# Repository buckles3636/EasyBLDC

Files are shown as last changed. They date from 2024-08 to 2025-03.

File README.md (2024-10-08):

# Easy BLDC

## Overview
Easy BLDC is an open source sensorless FOC brushless dc motor driver designed for propeller thrust applications such as drones or underwater AUVS.

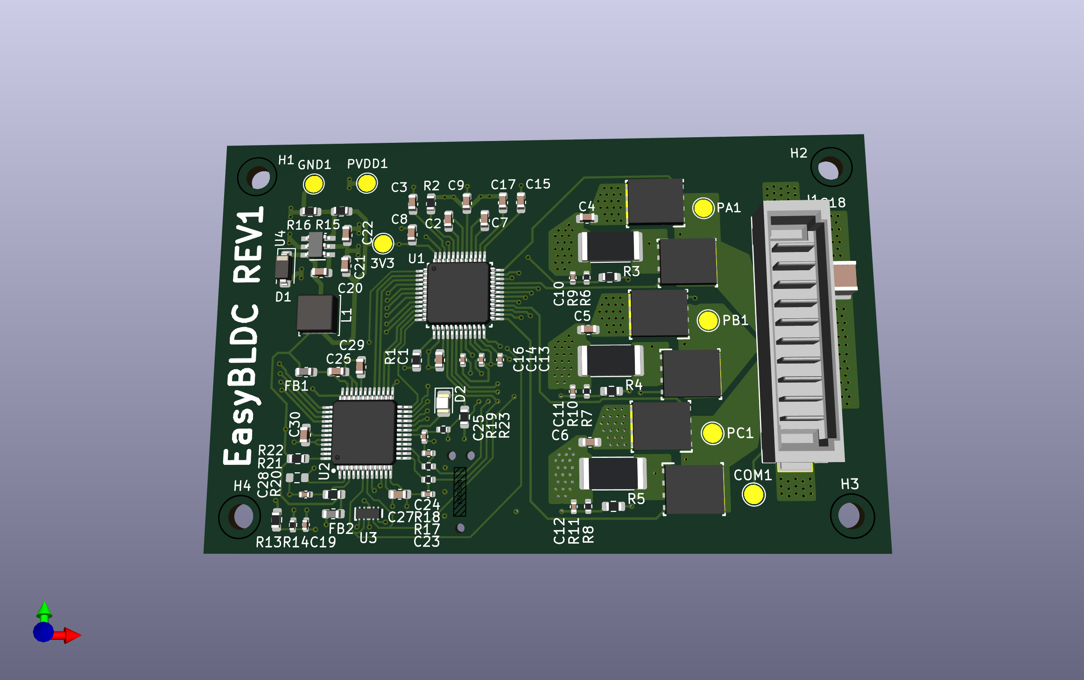
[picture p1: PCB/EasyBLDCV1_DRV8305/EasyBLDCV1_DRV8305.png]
PCB Render


## Features
* 30V Maximum Input Voltage
* 20A Maximum Continues Current (Untested)
* High current Amphenol power blade connector for board-board mounting
* High efficency FOC algorithm
* Modifiable parameters via Ti MotorWare® GUI

## Why FOC?
FOC is the most advanced of the three common algorithms. Unlike trapezoidal or sinusoidal control, which energize the motor’s phases based on predefined waveforms, FOC actively keeps tracks the stator position. This allows for precise control of both torque and speed by decoupling the motor’s magnetic field into two components: one that controls the motor's flux and the other that controls the torque. FOC is extremely efficient, especially at higher speeds, and results in smooth operation at lower speeds. 

## Key Components
* Texas Instruments DRV8305 gate driver
* Texas Instruments InstaSpin® TMS320F28027F MCU

## Ordering Guide
TODO:

## Getting Started Guide
TODO:

## Motor Tuning Guide
TODO:

## Contribution Guidelines
We welcome contributions from the broader community. To contribute:

1. **Fork the Repository**: Create your own fork of the project.
2. **Create a Feature Branch**: Make your changes in a new branch.
3. **Commit Your Changes**: Commit your changes with clear and detailed commit messages.
4. **Submit a Pull Request**: Create a pull request for your changes to be reviewed.

Please ensure your designs meet common standards and include necessary documentation and comments.

## Project Status
- Version 1: Released
- Version 2: In  Progress

## License
This project is licensed under the [MIT License](LICENSE) - see the LICENSE file for details.

## Contact
- Designer: Peter Buckley
- Email: peterbuckley3636@gmail.com

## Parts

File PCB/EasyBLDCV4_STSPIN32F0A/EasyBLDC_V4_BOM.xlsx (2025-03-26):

Designator | Footprint | Quantity | Value | Part #
C1, C10, C11, C2, C3, C6, C7, C8, C9 | 1206 | 9 | 22u 25V | CL31A226KAHNNNE
C12 | 805 | 1 | 10u 6.3V | CL21B106KQQNNNE
C13, C15, C16, C18, C4, C5 | 402 | 6 | 100n 6.3V | GRM155R60J104KA01D
C14 | 805 | 1 | 22u 6.3V | CL21A226MQQNNNE
C17 | 402 | 1 | 100n 25V | CL05B104KA5NNNC
C19, C20, C21 | 402 | 3 | 1u 25V | GRM155R61E105MA12D
D1, D2 | 402 | 2 | D | BAT54LP-7
D3 | 603 | 1 | GREEN | 150060GS75000
D4 | 603 | 1 | RED | 150060RS75000
J1 | AMPHENOL_10159560-A00221RLF | 1 |  | 10159560-A00221RLF
J2 | STLINK-V3MINIE-EDGE | 1 | STLINK-V3MINIE-EDGE
L1 |  | 1 | 22uF | MLZ2012P220WT000
Q1, Q2, Q3 | PG-TDSON-8-56-2 | 3 |  | IAUC60N04S6N031HATMA1
R1, R2, R3, R4, R5, R6 | 402 | 6 | 33 | RC0402FR-0733RL
R10, R19 | 402 | 2 | 1k | RC0402JR-071KL
R11, R12, R13, R18, R23, R7, R8, R9, R21 | 402 | 9 | 10k | RC0402JR-0710KL
R14 | 2512 | 1 | 0.001 | CRE2512-FZ-R001E-2
R15, R16, R17, R22 | 402 | 4 | 2.2k | RC0402FR-132K2L
R20 | 402 | 1 | 100k | RC0402JR-07100KL
TP1 | TestPoint_Pad_D1.5mm | 1 | TELEMETRY
TP2 | TestPoint_Pad_D1.5mm | 1 | TestPoint
U1 | DBV0005A_N | 1 |  | INA180A1IDBVR
U2 | IC_STSPIN32F0A | 1 |  | STSPIN32F0ATR

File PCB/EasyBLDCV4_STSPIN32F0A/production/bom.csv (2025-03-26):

Designator | Footprint | Quantity | Value | LCSC Part #
C1, C10, C11, C2, C3, C6, C7, C8, C9 | 1206 | 9 | 22u
C12 | 0805 | 1 | 10u
C13, C15, C16, C17, C18, C4, C5 | 0402 | 7 | 100n
C14, L1 | 0805 | 2 | 22u
C19, C20, C21 | 0402 | 3 | 1u
D1, D2 | 0402 | 2 | D
D3 | 0603 | 1 | GREEN
D4 | 0603 | 1 | RED
J1 | AMPHENOL_10159560-A00221RLF | 1 | 10159560-A00221RLF
J2 | STLINK-V3MINIE-EDGE | 1 | STLINK-V3MINIE-EDGE
Q1, Q2, Q3 | PG-TDSON-8-56-2 | 3 | IAUC60N04S6N031HATMA1
R1, R2, R3, R4, R5, R6 | 0402 | 6 | 33
R10, R19 | 0402 | 2 | 1k
R11, R12, R13, R18, R21, R23, R7, R8, R9 | 0402 | 9 | 10k
R14 | 2512 | 1 | 0.001
R15, R16, R17, R22 | 0402 | 4 | 2.2k
R20 | 0402 | 1 | 100k
TP1 | TestPoint_Pad_D1.5mm | 1 | TELEMETRY
TP2 | TestPoint_Pad_D1.5mm | 1 | TestPoint
U1 | DBV0005A_N | 1 | INA180A1IDBVR
U2 | IC_STSPIN32F0A | 1 | STSPIN32F0A

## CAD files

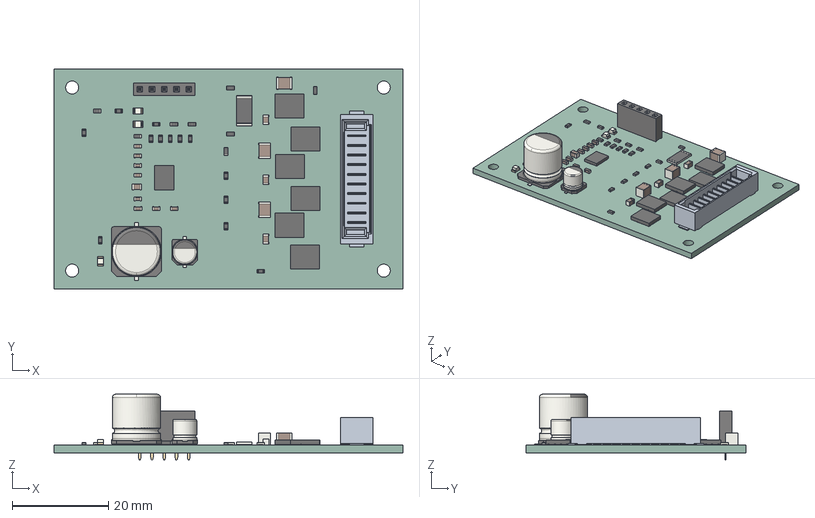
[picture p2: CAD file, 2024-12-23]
PCB/EasyBLDCV4_STSPIN32F0A/EasyBLDCV4_STSPIN32F0A.step
72.4 x 45.7 x 13.6 mm
R_0603_1608Metric x 21
DNK0008A_ASM x 6
CP_Elec_5x53
C_0603_1608Metric x 8
C_0805_2012Metric x 4
R_2512_6332Metric
REE0036A_ASM
LED_0805_2012Metric x 3
CP_Elec_10x105
C_1210_3225Metric x 3
10159560-A00221RLF
PinSocket_1x05_P254mm_Vertical
EasyBLDCV2_MCF8329_PCB

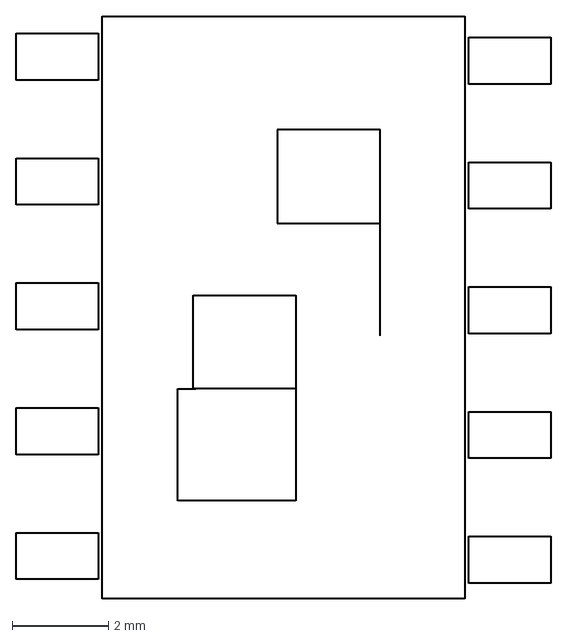
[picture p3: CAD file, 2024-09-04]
PCB/EasyBLDCV4_STSPIN32F0A/PBELogo.dxf
11.1 x 12.1 mm

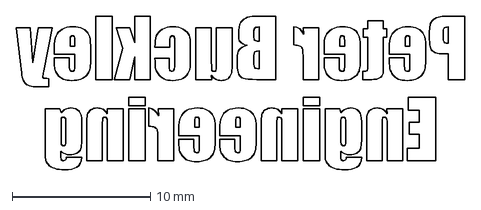
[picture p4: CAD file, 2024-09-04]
PCB/EasyBLDCV4_STSPIN32F0A/PBEText.dxf
32.5 x 11.1 mm

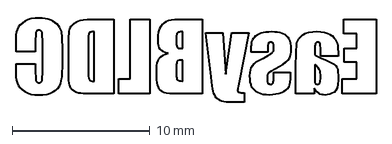
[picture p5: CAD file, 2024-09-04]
PCB/EasyBLDCV4_STSPIN32F0A/EasyESCText.dxf
26.1 x 6.17 mm

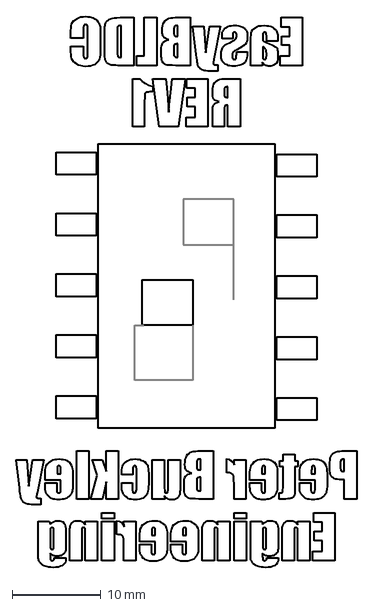
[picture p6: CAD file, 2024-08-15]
PCB/EasyBLDCV4_STSPIN32F0A/BottomLogo.dxf
38.5 x 62.2 mm

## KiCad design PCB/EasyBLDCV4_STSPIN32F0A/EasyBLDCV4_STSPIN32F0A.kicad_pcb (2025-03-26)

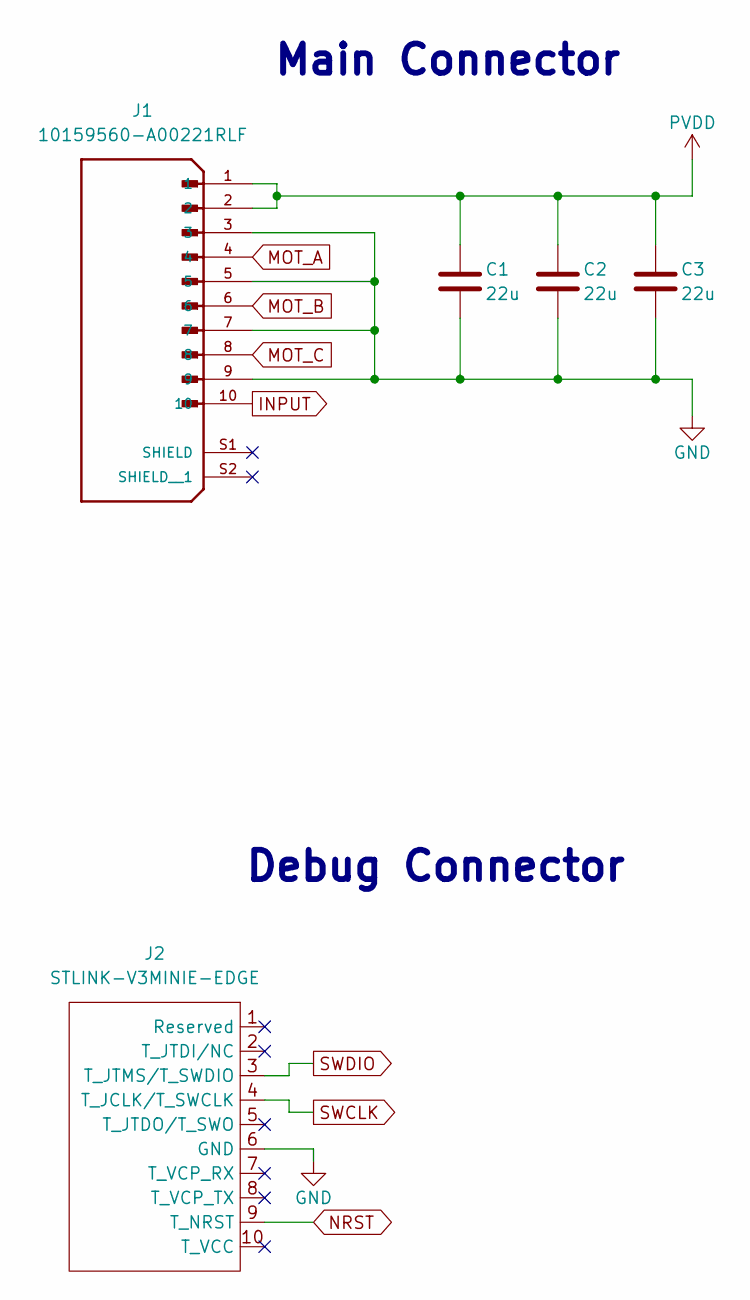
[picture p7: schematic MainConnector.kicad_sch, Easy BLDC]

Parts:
C1, C2, C3: 22u; C_1206_3216Metric
J1: 10159560-A00221RLF; AMPHENOL_10159560-A00221RLF; PARTREV C
J2: STLINK-V3MINIE-EDGE

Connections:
GND: C1.2, C2.2, C3.2, J1.3, J1.5, J1.7, J1.9, J2.6 (GND); also elsewhere on the board
INPUT: J1.10
MOT_A: J1.4; also elsewhere on the board
MOT_B: J1.6; also elsewhere on the board
MOT_C: J1.8; also elsewhere on the board
NRST: J2.9 (T_NRST); also elsewhere on the board
PVDD: C1.1, C2.1, C3.1, J1.1, J1.2; also elsewhere on the board
SWCLK: J2.4 (T_JCLK/T_SWCLK); also elsewhere on the board
SWDIO: J2.3 (T_JTMS/T_SWDIO); also elsewhere on the board

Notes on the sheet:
Main Connector
Debug Connector

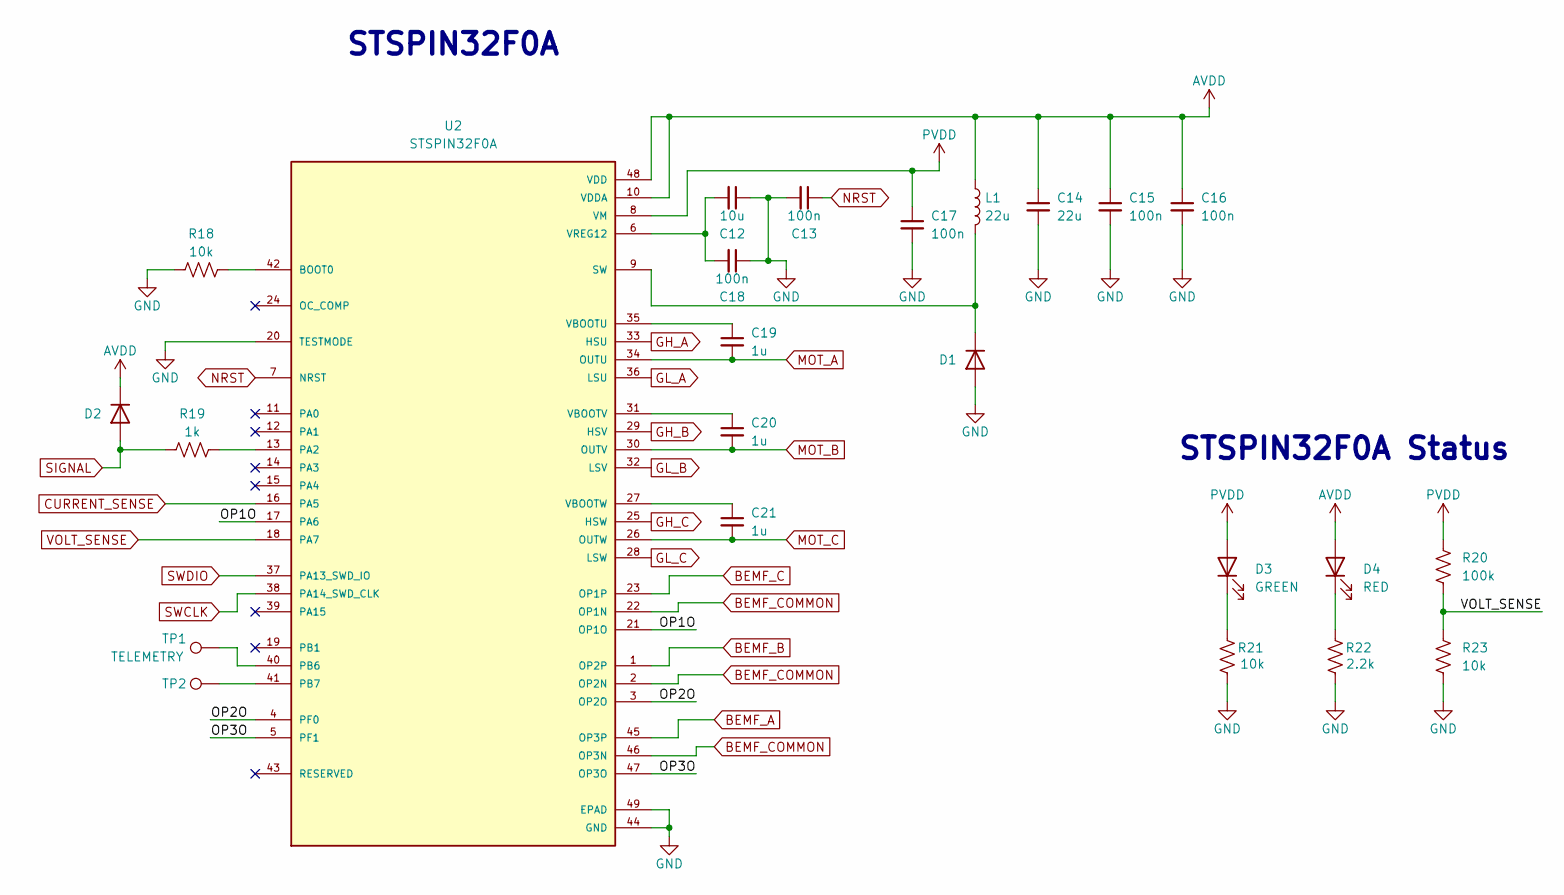
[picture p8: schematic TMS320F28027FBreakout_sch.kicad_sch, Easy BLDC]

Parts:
C12: 10u; C_0805_2012Metric
C13, C15, C16, C17, C18: 100n; C_0402_1005Metric
C14: 22u; C_0805_2012Metric
C19, C20, C21: 1u; C_0402_1005Metric
D1, D2: D; D_0402_1005Metric
D3: GREEN; LED_0603_1608Metric
D4: RED; LED_0603_1608Metric
L1: 22u; L_0805_2012Metric
R18, R21, R23: 10k; R_0402_1005Metric
R19: 1k; R_0402_1005Metric
R20: 100k; R_0402_1005Metric
R22: 2.2k; R_0402_1005Metric
TP1: TELEMETRY; TestPoint_Pad_D1.5mm
TP2: TestPoint; TestPoint_Pad_D1.5mm
U2: STSPIN32F0A; IC_STSPIN32F0A; PARTREV 2

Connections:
/MCU/OP1O: U2.17 (PA6), U2.21 (OP1O)
/MCU/OP2O: U2.3 (OP2O), U2.4 (PF0)
/MCU/OP3O: U2.5 (PF1), U2.47 (OP3O)
AVDD: C14.1, C15.1, C16.1, D2.1 (K), D4.2 (A), L1.1, U2.10 (VDDA), U2.48 (VDD); also elsewhere on the board
BEMF_A: U2.45 (OP3P); also elsewhere on the board
BEMF_B: U2.1 (OP2P); also elsewhere on the board
BEMF_C: U2.23 (OP1P); also elsewhere on the board
BEMF_COMMON: U2.2 (OP2N), U2.22 (OP1N), U2.46 (OP3N); also elsewhere on the board
CURRENT_SENSE: U2.16 (PA5); also elsewhere on the board
GH_A: U2.33 (HSU); also elsewhere on the board
GH_B: U2.29 (HSV); also elsewhere on the board
GH_C: U2.25 (HSW); also elsewhere on the board
GL_A: U2.36 (LSU); also elsewhere on the board
GL_B: U2.32 (LSV); also elsewhere on the board
GL_C: U2.28 (LSW); also elsewhere on the board
GND: C12.1, C13.2, C14.2, C15.2, C16.2, C17.2, C18.1, D1.2 (A), R18.1, R21.1, R22.1, R23.2, U2.20 (TESTMODE), U2.44 (GND), U2.49 (EPAD); also elsewhere on the board
MOT_A: C19.2, U2.34 (OUTU); also elsewhere on the board
MOT_B: C20.2, U2.30 (OUTV); also elsewhere on the board
MOT_C: C21.2, U2.26 (OUTW); also elsewhere on the board
NRST: C13.1, U2.7 (NRST); also elsewhere on the board
unnamed: D1.1 (K), L1.2, U2.9 (SW)
unnamed: D3.1 (K), R21.2
unnamed: D4.1 (K), R22.2
unnamed: R18.2, U2.42 (BOOT0)
unnamed: R19.2, U2.13 (PA2)
unnamed: TP1.1, U2.40 (PB6)
unnamed: TP2.1, U2.41 (PB7)
unnamed: C19.1, U2.35 (VBOOTU)
unnamed: C20.1, U2.31 (VBOOTV)
unnamed: C21.1, U2.27 (VBOOTW)
unnamed: C12.2, C18.2, U2.6 (VREG12)
PVDD: C17.1, D3.2 (A), R20.1, U2.8 (VM); also elsewhere on the board
SIGNAL: D2.2 (A), R19.1
SWCLK: U2.38 (PA14_SWD_CLK); also elsewhere on the board
SWDIO: U2.37 (PA13_SWD_IO); also elsewhere on the board
VOLT_SENSE: R20.2, R23.1, U2.18 (PA7)

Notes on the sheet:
STSPIN32F0A Status
STSPIN32F0A

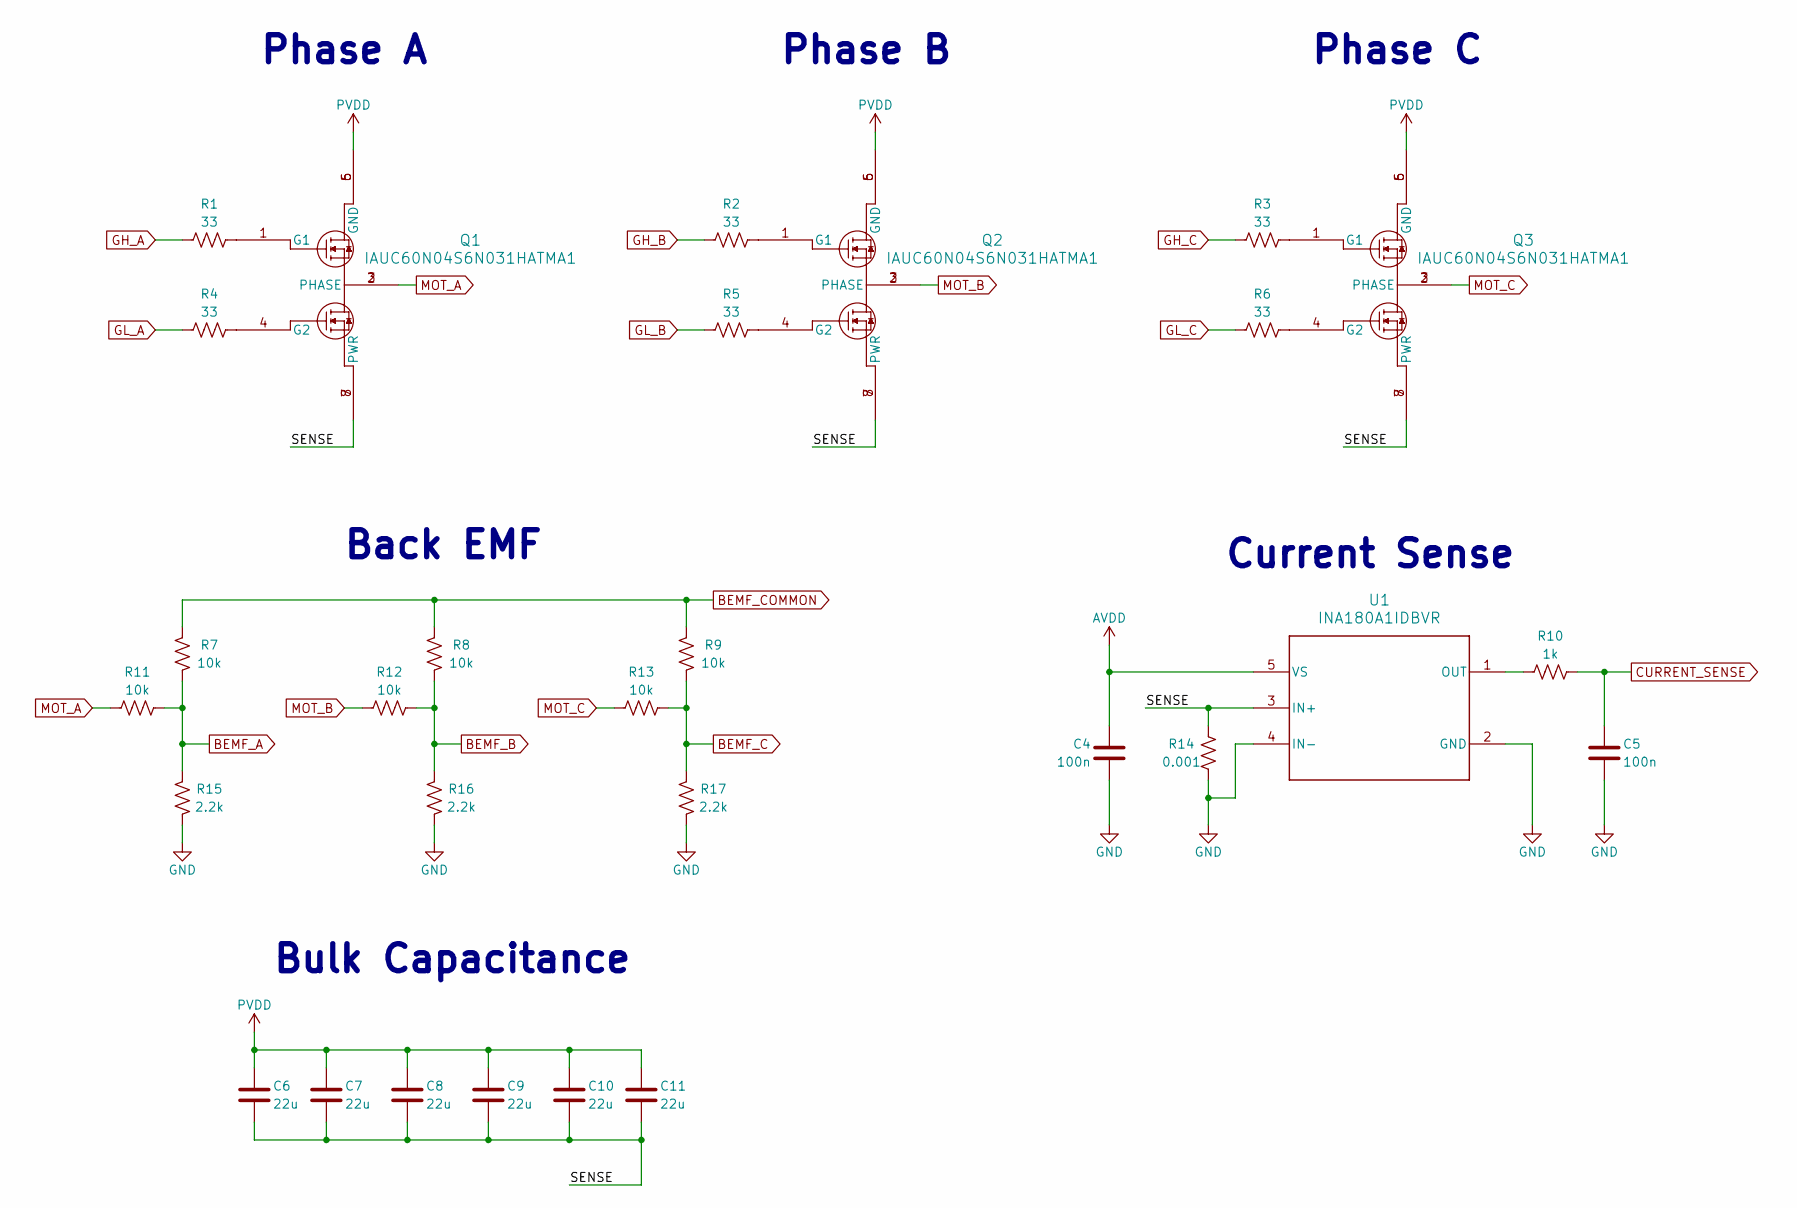
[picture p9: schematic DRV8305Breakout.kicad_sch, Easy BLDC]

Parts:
C4, C5: 100n; C_0402_1005Metric
C6, C7, C8, C9, C10, C11: 22u; C_1206_3216Metric
Q1, Q2, Q3: IAUC60N04S6N031HATMA1; PG-TDSON-8-56-2
R1, R2, R3, R4, R5, R6: 33; R_0402_1005Metric
R7, R8, R9, R11, R12, R13: 10k; R_0402_1005Metric
R10: 1k; R_0402_1005Metric
R14: 0.001; R_2512_6332Metric
R15, R16, R17: 2.2k; R_0402_1005Metric
U1: INA180A1IDBVR; DBV0005A_N

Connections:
/Power Stage/SENSE: C6.2, C7.2, C8.2, C9.2, C10.2, C11.2, Q1.7 (PWR), Q1.8 (PWR), Q2.7 (PWR), Q2.8 (PWR), Q3.7 (PWR), Q3.8 (PWR), R14.2, U1.3 (IN+)
AVDD: C4.1, U1.5 (VS); also elsewhere on the board
BEMF_A: R7.1, R11.2, R15.2; also elsewhere on the board
BEMF_B: R8.1, R12.2, R16.2; also elsewhere on the board
BEMF_C: R9.1, R13.2, R17.2; also elsewhere on the board
BEMF_COMMON: R7.2, R8.2, R9.2; also elsewhere on the board
CURRENT_SENSE: C5.1, R10.2; also elsewhere on the board
GH_A: R1.1; also elsewhere on the board
GH_B: R2.1; also elsewhere on the board
GH_C: R3.1; also elsewhere on the board
GL_A: R4.1; also elsewhere on the board
GL_B: R5.1; also elsewhere on the board
GL_C: R6.1; also elsewhere on the board
GND: C4.2, C5.2, R14.1, R15.1, R16.1, R17.1, U1.2 (GND), U1.4 (IN-); also elsewhere on the board
MOT_A: Q1.2 (PHASE), Q1.3 (PHASE), R11.1; also elsewhere on the board
MOT_B: Q2.2 (PHASE), Q2.3 (PHASE), R12.1; also elsewhere on the board
MOT_C: Q3.2 (PHASE), Q3.3 (PHASE), R13.1; also elsewhere on the board
unnamed: Q1.1 (G1), R1.2
unnamed: Q1.4 (G2), R4.2
unnamed: Q2.1 (G1), R2.2
unnamed: Q2.4 (G2), R5.2
unnamed: Q3.1 (G1), R3.2
unnamed: Q3.4 (G2), R6.2
unnamed: R10.1, U1.1 (OUT)
PVDD: C6.1, C7.1, C8.1, C9.1, C10.1, C11.1, Q1.5 (GND), Q1.6 (GND), Q2.5 (GND), Q2.6 (GND), Q3.5 (GND), Q3.6 (GND); also elsewhere on the board

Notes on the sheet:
Current Sense
Phase C
Bulk Capacitance
Phase B
Back EMF
Phase A

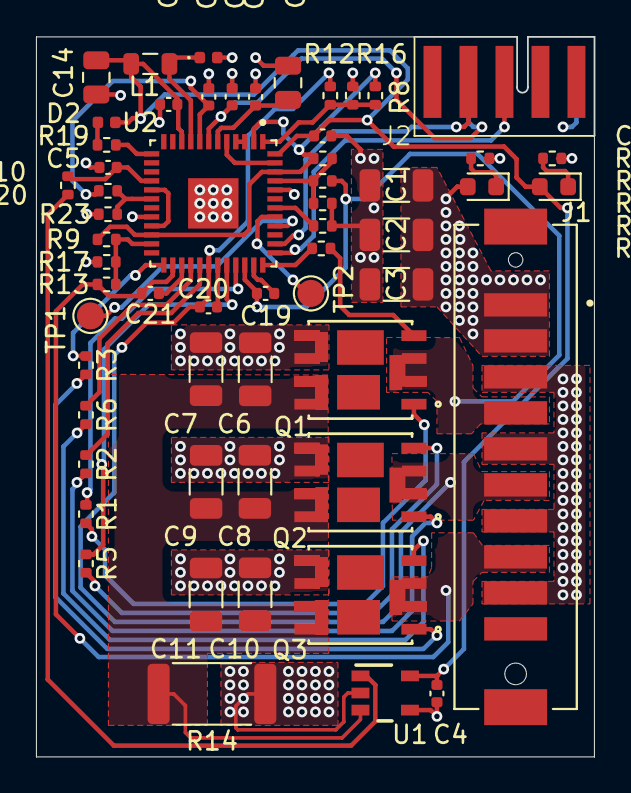
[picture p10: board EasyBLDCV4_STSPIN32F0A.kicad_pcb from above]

Board: 4 copper layers, 31.0 x 40.0 mm, 58 parts (0 on the bottom side), 44 nets.

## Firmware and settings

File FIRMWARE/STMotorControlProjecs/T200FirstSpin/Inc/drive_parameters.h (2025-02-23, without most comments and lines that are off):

#define DRIVE_PARAMETERS_H
#define MAX_APPLICATION_SPEED_RPM           1062
#define MIN_APPLICATION_SPEED_RPM           0
#define M1_SS_MEAS_ERRORS_BEFORE_FAULTS     3
#define VARIANCE_THRESHOLD                  0.25
#define F1                                  16384
#define F2                                  4096
#define F1_LOG                              LOG2((16384))
#define F2_LOG                              LOG2((4096))
#define GAIN1                               -22016
#define GAIN2                               17800
#define PLL_KP_GAIN                         494
#define PLL_KI_GAIN                         22
#define PLL_KPDIV                           16384
#define PLL_KPDIV_LOG                       LOG2((PLL_KPDIV))
#define PLL_KIDIV                           65535
#define PLL_KIDIV_LOG                       LOG2((PLL_KIDIV))
#define STO_FIFO_DEPTH_DPP                  64
#define STO_FIFO_DEPTH_DPP_LOG              LOG2((64))
#define STO_FIFO_DEPTH_UNIT                 64
#define M1_BEMF_CONSISTENCY_TOL             64
#define M1_BEMF_CONSISTENCY_GAIN            64
#define PARK_ANGLE_COMPENSATION_FACTOR      0
#define REV_PARK_ANGLE_COMPENSATION_FACTOR  0
#define PWM_FREQUENCY                       16000
#define PWM_FREQ_SCALING                    1
#define LOW_SIDE_SIGNALS_ENABLING           LS_PWM_TIMER
#define SW_DEADTIME_NS                      750
#define REGULATION_EXECUTION_RATE           1
#define ISR_FREQUENCY_HZ                    (PWM_FREQUENCY/REGULATION_EXECUTION_RATE)
#define PID_TORQUE_KP_DEFAULT               3719
#define PID_TORQUE_KI_DEFAULT               3099
#define PID_TORQUE_KD_DEFAULT               100
#define PID_FLUX_KP_DEFAULT                 3719
#define PID_FLUX_KI_DEFAULT                 3099
#define PID_FLUX_KD_DEFAULT                 100
#define TF_KPDIV                            4096
#define TF_KIDIV                            16384
#define TF_KDDIV                            8192
#define TF_KPDIV_LOG                        LOG2((4096))
#define TF_KIDIV_LOG                        LOG2((16384))
#define TF_KDDIV_LOG                        LOG2((8192))
#define TFDIFFERENTIAL_TERM_ENABLING        DISABLE
#define PID_SPEED_KP_DEFAULT                2174/(SPEED_UNIT/10)
#define PID_SPEED_KI_DEFAULT                876/(SPEED_UNIT/10)
#define PID_SPEED_KD_DEFAULT                0/(SPEED_UNIT/10)
#define SPEED_LOOP_FREQUENCY_HZ             (uint16_t)1000
#define SP_KPDIV                            8
#define SP_KIDIV                            16384
#define SP_KDDIV                            16
#define SP_KPDIV_LOG                        LOG2((8))
#define SP_KIDIV_LOG                        LOG2((16384))
#define SP_KDDIV_LOG                        LOG2((16))
#define PID_SPEED_INTEGRAL_INIT_DIV         1
#define SPD_DIFFERENTIAL_TERM_ENABLING      DISABLE
#define IQMAX_A                             8
#define DEFAULT_CONTROL_MODE                MCM_SPEED_MODE
#define DEFAULT_TARGET_SPEED_RPM            383
#define DEFAULT_TARGET_SPEED_UNIT           (DEFAULT_TARGET_SPEED_RPM*SPEED_UNIT/U_RPM)
#define DEFAULT_TORQUE_COMPONENT_A          0
#define DEFAULT_FLUX_COMPONENT_A            0
#define OV_VOLTAGE_THRESHOLD_V              28
#define UD_VOLTAGE_THRESHOLD_V              8
#ifdef NOT_IMPLEMENTED
#define ON_OVER_VOLTAGE                     TURN_OFF_PWM
#endif
#define OV_TEMPERATURE_THRESHOLD_C          70
#define OV_TEMPERATURE_HYSTERESIS_C         10
#define HW_OV_CURRENT_PROT_BYPASS           DISABLE
#define OVP_INVERTINGINPUT_MODE             INT_MODE
#define OVP_INVERTINGINPUT_MODE2            INT_MODE
#define OVP_SELECTION                       COMP_Selection_COMP1
#define OVP_SELECTION2                      COMP_Selection_COMP1
#define PHASE1_DURATION                     1000
#define PHASE1_FINAL_SPEED_UNIT             (0*SPEED_UNIT/U_RPM)
#define PHASE1_FINAL_CURRENT_A              8
#define PHASE2_DURATION                     850
#define PHASE2_FINAL_SPEED_UNIT             (425*SPEED_UNIT/U_RPM)
#define PHASE2_FINAL_CURRENT_A              8
#define PHASE3_DURATION                     0
#define PHASE3_FINAL_SPEED_UNIT             (425*SPEED_UNIT/U_RPM)
#define PHASE3_FINAL_CURRENT_A              8
#define PHASE4_DURATION                     0
#define PHASE4_FINAL_SPEED_UNIT             (425*SPEED_UNIT/U_RPM)
#define PHASE4_FINAL_CURRENT_A              8
#define PHASE5_DURATION                     0
#define PHASE5_FINAL_SPEED_UNIT             (425*SPEED_UNIT/U_RPM)
#define PHASE5_FINAL_CURRENT_A              8
#define ENABLE_SL_ALGO_FROM_PHASE           2
#define STARTING_ANGLE_DEG                  0
#define OBS_MINIMUM_SPEED_RPM               383
#define NB_CONSECUTIVE_TESTS                2
#define SPEED_BAND_UPPER_LIMIT              17
#define SPEED_BAND_LOWER_LIMIT              15
#define TRANSITION_DURATION                 25
#define  M1_VBUS_SAMPLING_TIME              LL_ADC_SAMPLING_CYCLE(47)
#define  M1_TEMP_SAMPLING_TIME              LL_ADC_SAMPLING_CYCLE(47)
#define ADC_SAMPLING_CYCLES                 (6 + SAMPLING_CYCLE_CORRECTION)

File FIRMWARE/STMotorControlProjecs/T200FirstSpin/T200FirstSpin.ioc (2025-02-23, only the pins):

Mcu.UserName=STM32G431CBUx
PA0.GPIO_Label=M1_BUS_VOLTAGE
PA0.Signal=ADC1_IN1
PA1.GPIO_Label=M1_CURR_SHUNT_U
PA1.Signal=SharedAnalog_PA1
PA10.GPIO_Label=M1_PWM_WH
PA10.Signal=S_TIM1_CH3
PA12.GPIO_Label=M1_PWM_VL
PA12.Signal=TIM1_CH2N
PA13.GPIO_Label=TMS
PA13.Signal=SYS_JTMS-SWDIO
PA14.GPIO_Label=TCK
PA14.Signal=SYS_JTCK-SWCLK
PA2.GPIO_Label=M1_OPAMP1_OUT
PA2.Signal=SharedAnalog_PA2
PA3.GPIO_Label=M1_OPAMP1_INT_GAIN
PA3.Signal=OPAMP1_VINM0
PA5.GPIO_Label=M1_OPAMP2_INT_GAIN
PA5.Signal=OPAMP2_VINM0
PA6.GPIO_Label=M1_OPAMP2_OUT
PA6.Signal=SharedAnalog_PA6
PA7.GPIO_Label=M1_CURR_SHUNT_V
PA7.Signal=SharedAnalog_PA7
PA8.GPIO_Label=M1_PWM_UH
PA8.Signal=S_TIM1_CH1
PA9.GPIO_Label=M1_PWM_VH
PA9.Signal=S_TIM1_CH2
PB0.GPIO_Label=M1_CURR_SHUNT_W
PB0.Signal=SharedAnalog_PB0
PB1.GPIO_Label=M1_OPAMP3_OUT
PB1.Signal=SharedAnalog_PB1
PB14.GPIO_Label=M1_TEMPERATURE
PB14.Signal=ADC1_IN5
PB15.GPIO_Label=M1_PWM_WL
PB15.Signal=TIM1_CH3N
PB2.GPIO_Label=M1_OPAMP3_INT_GAIN
PB2.Signal=OPAMP3_VINM0
PB3.GPIO_Label=UART_TX
PB3.Signal=USART2_TX
PB4.GPIO_Label=UART_RX
PB4.Signal=USART2_RX
PC10.GPIO_Label=Start/Stop [PushButton]
PC10.Signal=GPXTI10
PC13.GPIO_Label=M1_PWM_UL
PC13.Signal=TIM1_CH1N
PF0-OSC_IN.Signal=RCC_OSC_IN
PF1-OSC_OUT.Signal=RCC_OSC_OUT

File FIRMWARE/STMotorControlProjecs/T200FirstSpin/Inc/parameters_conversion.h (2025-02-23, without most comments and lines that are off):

#define PARAMETERS_CONVERSION_H
#include "mc_math.h"
#include "parameters_conversion_g4xx.h"
#include "pmsm_motor_parameters.h"
#include "drive_parameters.h"
#include "power_stage_parameters.h"
#define CURRENT_CONV_FACTOR                 (uint16_t)((65536.0 * RSHUNT * AMPLIFICATION_GAIN)/ADC_REFERENCE_VOLTAGE)
#define CURRENT_CONV_FACTOR_INV             (1.0 / ((65536.0 * RSHUNT * AMPLIFICATION_GAIN) / ADC_REFERENCE_VOLTAGE))
#define NOMINAL_CURRENT                     (NOMINAL_CURRENT_A * CURRENT_CONV_FACTOR)
#define ADC_REFERENCE_VOLTAGE               3.3
#define M1_MAX_READABLE_CURRENT  (ADC_REFERENCE_VOLTAGE / (2 * RSHUNT * AMPLIFICATION_GAIN))
#define TF_REGULATION_RATE                  (uint32_t)((uint32_t)(PWM_FREQUENCY) / (REGULATION_EXECUTION_RATE))
#define TF_REGULATION_RATE_SCALED           (uint16_t)((uint32_t)(PWM_FREQUENCY) / (REGULATION_EXECUTION_RATE\
                                            * PWM_FREQ_SCALING))
#define DPP_CONV_FACTOR                     (65536 / PWM_FREQ_SCALING)
#define ID_DEMAG                            (ID_DEMAG_A * CURRENT_CONV_FACTOR)
#define IQMAX                               (IQMAX_A * CURRENT_CONV_FACTOR)
#define DEFAULT_TORQUE_COMPONENT            (DEFAULT_TORQUE_COMPONENT_A * CURRENT_CONV_FACTOR)
#define DEFAULT_FLUX_COMPONENT              (DEFAULT_FLUX_COMPONENT_A * CURRENT_CONV_FACTOR)
#define REP_COUNTER                         (uint16_t)((REGULATION_EXECUTION_RATE * 2u) - 1u)
#define SYS_TICK_FREQUENCY                  (uint16_t)2000
#define UI_TASK_FREQUENCY_HZ                10U
#define PHASE1_FINAL_CURRENT                (PHASE1_FINAL_CURRENT_A * CURRENT_CONV_FACTOR)
#define PHASE2_FINAL_CURRENT                (PHASE2_FINAL_CURRENT_A * CURRENT_CONV_FACTOR)
#define PHASE3_FINAL_CURRENT                (PHASE3_FINAL_CURRENT_A * CURRENT_CONV_FACTOR)
#define PHASE4_FINAL_CURRENT                (PHASE4_FINAL_CURRENT_A * CURRENT_CONV_FACTOR)
#define PHASE5_FINAL_CURRENT                (PHASE5_FINAL_CURRENT_A * CURRENT_CONV_FACTOR)
#define MEDIUM_FREQUENCY_TASK_RATE          (uint16_t)SPEED_LOOP_FREQUENCY_HZ
#define MF_TASK_OCCURENCE_TICKS             (SYS_TICK_FREQUENCY / SPEED_LOOP_FREQUENCY_HZ) - 1u
#define UI_TASK_OCCURENCE_TICKS             (SYS_TICK_FREQUENCY / UI_TASK_FREQUENCY_HZ) - 1u
#define SERIALCOM_TIMEOUT_OCCURENCE_TICKS   (SYS_TICK_FREQUENCY / SERIAL_COM_TIMEOUT_INVERSE) - 1u
#define SERIALCOM_ATR_TIME_TICKS            (uint16_t)(((SYS_TICK_FREQUENCY * SERIAL_COM_ATR_TIME_MS) / 1000u) - 1u)
#define MAX_BEMF_VOLTAGE                    (uint16_t)((MAX_APPLICATION_SPEED_RPM * 1.2 *\
                                            MOTOR_VOLTAGE_CONSTANT * SQRT_2) / (1000u * SQRT_3))
#define MAX_VOLTAGE                         (int16_t)((ADC_REFERENCE_VOLTAGE / SQRT_3) / VBUS_PARTITIONING_FACTOR)
#define MAX_CURRENT                         (ADC_REFERENCE_VOLTAGE / (2 * RSHUNT * AMPLIFICATION_GAIN))
#define OBS_MINIMUM_SPEED_UNIT              (uint16_t)((OBS_MINIMUM_SPEED_RPM * SPEED_UNIT) / U_RPM)
#define MAX_APPLICATION_SPEED_UNIT          ((MAX_APPLICATION_SPEED_RPM * SPEED_UNIT) / U_RPM)
#define MIN_APPLICATION_SPEED_UNIT          ((MIN_APPLICATION_SPEED_RPM * SPEED_UNIT) / U_RPM)
#define C1                                  (int32_t)((((int16_t)F1) * RS) / (LS * TF_REGULATION_RATE))
#define C2                                  (int32_t)GAIN1
#define C3                                  (int32_t)((((int16_t)F1) * MAX_BEMF_VOLTAGE)\
                                            / (LS * MAX_CURRENT * TF_REGULATION_RATE))
#define C4                                  (int32_t)GAIN2
#define C5                                  (int32_t)((((int16_t)F1) * MAX_VOLTAGE)\
                                            / (LS * MAX_CURRENT * TF_REGULATION_RATE))
#define PERCENTAGE_FACTOR                   (uint16_t)(VARIANCE_THRESHOLD*128u)
#define HFI_MINIMUM_SPEED                   (uint16_t) (HFI_MINIMUM_SPEED_RPM/6u)
#define MAX_APPLICATION_SPEED_UNIT2         ((MAX_APPLICATION_SPEED_RPM2 * SPEED_UNIT) / U_RPM)
#define MIN_APPLICATION_SPEED_UNIT2         ((MIN_APPLICATION_SPEED_RPM2 * SPEED_UNIT) / U_RPM)
#define OVERVOLTAGE_THRESHOLD_d             (uint16_t)(OV_VOLTAGE_THRESHOLD_V * 65535 /\
                                            (ADC_REFERENCE_VOLTAGE / VBUS_PARTITIONING_FACTOR))
#define OVERVOLTAGE_THRESHOLD_LOW_d         (uint16_t)(OV_VOLTAGE_THRESHOLD_V * 65535 /\
                                            (ADC_REFERENCE_VOLTAGE / VBUS_PARTITIONING_FACTOR))
#define UNDERVOLTAGE_THRESHOLD_d            (uint16_t)((UD_VOLTAGE_THRESHOLD_V * 65535) /\
                                            ((uint16_t)(ADC_REFERENCE_VOLTAGE / VBUS_PARTITIONING_FACTOR)))
#define INT_SUPPLY_VOLTAGE                  (uint16_t)(65536 / ADC_REFERENCE_VOLTAGE)
#define DELTA_TEMP_THRESHOLD                (OV_TEMPERATURE_THRESHOLD_C - T0_C)
#define DELTA_V_THRESHOLD                   (dV_dT * DELTA_TEMP_THRESHOLD)
#define OV_TEMPERATURE_THRESHOLD_d          ((V0_V + DELTA_V_THRESHOLD) * INT_SUPPLY_VOLTAGE)
#define DELTA_TEMP_HYSTERESIS               (OV_TEMPERATURE_HYSTERESIS_C)
#define DELTA_V_HYSTERESIS                  (dV_dT * DELTA_TEMP_HYSTERESIS)
#define OV_TEMPERATURE_HYSTERESIS_d         (DELTA_V_HYSTERESIS * INT_SUPPLY_VOLTAGE)
#define PWM_PERIOD_CYCLES                   (uint16_t)(((uint32_t)ADV_TIM_CLK_MHz * (uint32_t)1000000u\
                                            / ((uint32_t)(PWM_FREQUENCY))) & (uint16_t)0xFFFE)
#define DEADTIME_NS                         SW_DEADTIME_NS
#define DEAD_TIME_ADV_TIM_CLK_MHz           (ADV_TIM_CLK_MHz * TIM_CLOCK_DIVIDER)
#define DEAD_TIME_COUNTS_1                  (DEAD_TIME_ADV_TIM_CLK_MHz * DEADTIME_NS / 1000uL)
#if (DEAD_TIME_COUNTS_1 <= 255)
#define DEAD_TIME_COUNTS                    (uint16_t)DEAD_TIME_COUNTS_1
#elif (DEAD_TIME_COUNTS_1 <= 508)
#define DEAD_TIME_COUNTS                    (uint16_t)(((DEAD_TIME_ADV_TIM_CLK_MHz * DEADTIME_NS/2) /1000uL) + 128)
#elif (DEAD_TIME_COUNTS_1 <= 1008)
#define DEAD_TIME_COUNTS                    (uint16_t)(((DEAD_TIME_ADV_TIM_CLK_MHz * DEADTIME_NS/8) /1000uL) + 320)
#elif (DEAD_TIME_COUNTS_1 <= 2015)
#define DEAD_TIME_COUNTS                    (uint16_t)(((DEAD_TIME_ADV_TIM_CLK_MHz * DEADTIME_NS/16) /1000uL) + 384)
#else
#define DEAD_TIME_COUNTS 510
#endif
#define DTCOMPCNT                           (uint16_t)((DEADTIME_NS * ADV_TIM_CLK_MHz) / 2000)
#define TON_NS                              500
#define TOFF_NS                             500
#define TON                                 (uint16_t)((TON_NS * ADV_TIM_CLK_MHz)  / 2000)
#define TOFF                                (uint16_t)((TOFF_NS * ADV_TIM_CLK_MHz) / 2000)
#define SAMPLING_TIME                       ((ADC_SAMPLING_CYCLES * ADV_TIM_CLK_MHz) / ADC_CLK_MHz)
#define TRISE                               ((TRISE_NS * ADV_TIM_CLK_MHz)/1000uL)
#define TDEAD                               ((uint16_t)((DEADTIME_NS * ADV_TIM_CLK_MHz)/1000))
#define TNOISE                              ((uint16_t)((TNOISE_NS*ADV_TIM_CLK_MHz)/1000))
#define HTMIN 1
#define TW_AFTER                            ((uint16_t)(((DEADTIME_NS+MAX_TNTR_NS)*ADV_TIM_CLK_MHz)/1000UL))
#define MAX_TWAIT                           ((uint16_t)((TW_AFTER - SAMPLING_TIME)/2))
#define TW_BEFORE                           ((uint16_t)((ADC_TRIG_CONV_LATENCY_CYCLES + ADC_SAMPLING_CYCLES)\
                                            * ADV_TIM_CLK_MHz) / ADC_CLK_MHz  + 1u)
#define TW_BEFORE_R3_1                      ((uint16_t)((ADC_TRIG_CONV_LATENCY_CYCLES + (ADC_SAMPLING_CYCLES * 2)\
                                            + ADC_SAR_CYCLES) * ADV_TIM_CLK_MHz) / ADC_CLK_MHz  + 1u)
#define M1_VIRTUAL_HEAT_SINK_TEMPERATURE_VALUE 25u
#define M1_TEMP_SW_FILTER_BW_FACTOR         250u
#define PQD_CONVERSION_FACTOR               (float_t)(((1.732 * ADC_REFERENCE_VOLTAGE) /\
                                            (RSHUNT * AMPLIFICATION_GAIN)) / 65536.0f)
#define DAC_ENABLE
#define DAC_OP_ENABLE
#define FW_ENABLE
#define DIFFTERM_ENABLE
#define MAIN_SCFG                           UI_SCODE_STO_PLL
#define AUX_SCFG                               0x0
#define PLLTUNING_ENABLE
#define UI_CFGOPT_PFC_ENABLE
#define UI_CONFIG_M1                        (UI_CFGOPT_NONE DAC_OP_ENABLE FW_ENABLE DIFFTERM_ENABLE\
                                            | (MAIN_SCFG << MAIN_SCFG_POS)\
                                            | (AUX_SCFG << AUX_SCFG_POS)\
                                            | UI_CFGOPT_SETIDINSPDMODE PLLTUNING_ENABLE UI_CFGOPT_PFC_ENABLE\
                                            | UI_CFGOPT_PLLTUNING)
#define UI_CONFIG_M2
#define DIN_ACTIVE_LOW                      Bit_RESET
#define DIN_ACTIVE_HIGH                     Bit_SET
#define DOUT_ACTIVE_HIGH                    DOutputActiveHigh
#define DOUT_ACTIVE_LOW                     DOutputActiveLow
#define LPF_FILT_CONST                      ((int16_t)(32767 * 0.5))
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

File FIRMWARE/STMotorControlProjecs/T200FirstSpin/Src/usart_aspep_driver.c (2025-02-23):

/**
  ******************************************************************************
  * @file    usart_aspep_driver.c
  * @author  Motor Control SDK Team, ST Microelectronics
  * @brief   This file provides firmware functions that implement the uart driver for the aspep protocol
  *
  *
  ******************************************************************************
  * @attention
  *
  * <h2><center>&copy; Copyright (c) 2024 STMicroelectronics.
  * All rights reserved.</center></h2>
  *
  * This software component is licensed by ST under Ultimate Liberty license
  * SLA0044, the "License"; You may not use this file except in compliance with
  * the License. You may obtain a copy of the License at:
  *                             www.st.com/SLA0044
  *
  ******************************************************************************
  */

#include <stdint.h>
#include "mc_stm_types.h"
#include "usart_aspep_driver.h"
#include "aspep.h"

void UASPEP_TX_INIT(UASPEP_Handle_t *pHandle);
void UASPEP_RX_INIT(UASPEP_Handle_t *pHandle);

/** @addtogroup MCSDK
  * @{
  */

/** @addtogroup MCP
  * @{
  */

/**
  * @brief  Initialization of the Hardware used for data transmission and reception.
  *
  * @param  pHandle Handler of the current instance of the UASPEP component
  */
void UASPEP_INIT(void *pHWHandle)
{
  UASPEP_Handle_t *pHandle = (UASPEP_Handle_t *)pHWHandle; //cstat !MISRAC2012-Rule-11.5
  UASPEP_RX_INIT(pHandle);
  UASPEP_TX_INIT(pHandle);
}

/**
  * @brief  Configures the Hardware used for data transmission to controller.
  *
  * @param  pHandle Handler of the current instance of the UASPEP component
  */
void UASPEP_TX_INIT(UASPEP_Handle_t *pHandle)
{
#ifdef NULL_PTR_CHECK_USA_ASP_DRV
  if (NULL == pHandle)
  {
    /* Nothing to do */
  }
  else
  {
#endif
    /* Enable DMA UART */
    LL_USART_ClearFlag_TC(pHandle->USARTx);
    LL_USART_EnableIT_TC(pHandle->USARTx);

    /* Enable DMA UART to start the TX request */
    LL_USART_EnableDMAReq_TX(pHandle->USARTx);

    /* Write the USART_TDR register address in the DMA control register to configure it as
     * the destination of the transfer */
    //cstat !MISRAC2012-Rule-11.4
    LL_DMA_SetPeriphAddress(pHandle->txDMA, pHandle->txChannel, (uint32_t)&pHandle->USARTx->TDR);

    /* Clear UART ISR */
    LL_USART_ClearFlag_TC(pHandle->USARTx);

    /* DMA end of transfer on UART TX channel completion is not activated */
    /* We prefer to activate UART TC itself to avoid to trig IT while queued data are still to be transmitted */
#ifdef NULL_PTR_CHECK_USA_ASP_DRV
  }
#endif
}

/**
  * @brief  Configures the Hardware used for data reception from controller.
  *
  * @param  pHandle Handler of the current instance of the UASPEP component
  */
void UASPEP_RX_INIT(UASPEP_Handle_t *pHandle)
{
#ifdef NULL_PTR_CHECK_USA_ASP_DRV
  if (NULL == pHandle)
  {
    /* Nothing to do */
  }
  else
  {
#endif
    /* DMA interrupt not used for all families */
    /* Enable DMA end of transfer on UART RX channel completion */
    /* LL_DMA_EnableIT_TC(pHandle->rxDMA, pHandle->rxChannel) */
    /* Enable Error interrupt (EIE) to unmask Overrun interrupt */
    LL_USART_EnableIT_ERROR(pHandle->USARTx);

    /* Write the USART_RDR register address in the DMA control register to configure it as
     * the source of the transfer */
    //cstat !MISRAC2012-Rule-11.4
    LL_DMA_SetPeriphAddress(pHandle->rxDMA, pHandle->rxChannel, (uint32_t)&pHandle->USARTx->RDR);

    /* Clear UART ISR */
    LL_USART_ClearFlag_TC(pHandle->USARTx);

    LL_USART_EnableDMAReq_RX(pHandle->USARTx);
#ifdef NULL_PTR_CHECK_USA_ASP_DRV
  }
#endif
}

/**
  * @brief  Configures data transmission.
  *
  * @param  pHWHandle Hardware components chosen for communication
  * @param  data Data to be transmitted to controller
  * @param  length Length of the data to be transmitted
  */
void UASPEP_CFG_TRANSMISSION(void *pHWHandle, void *data, uint16_t length)
{
  UASPEP_Handle_t *pHandle = (UASPEP_Handle_t *)pHWHandle; //cstat !MISRAC2012-Rule-11.5
  if (0U == LL_DMA_IsEnabledChannel(pHandle->txDMA, pHandle->txChannel))
  {
    //cstat !MISRAC2012-Rule-11.4 !MISRAC2012-Rule-11.6
    LL_DMA_SetMemoryAddress(pHandle->txDMA, pHandle->txChannel, (uint32_t)data);
    LL_DMA_SetDataLength(pHandle->txDMA, pHandle->txChannel, length);
    LL_DMA_EnableChannel(pHandle->txDMA, pHandle->txChannel);
  }
  else
  {
    /* Nothing to do */
  }
}

/**
  * @brief  Configures data reception.
  *
  * @param  pHWHandle Hardware components chosen for communication
  * @param  buffer Buffer which will receive the communicated data
  * @param  length Length of the received data
  */
void UASPEP_CFG_RECEPTION(void *pHWHandle, void* buffer, uint16_t length)
{
  UASPEP_Handle_t *pHandle = (UASPEP_Handle_t *)pHWHandle; //cstat !MISRAC2012-Rule-11.5
  LL_DMA_DisableChannel(pHandle->rxDMA, pHandle->rxChannel);
  //cstat !MISRAC2012-Rule-11.4 !MISRAC2012-Rule-11.6
  LL_DMA_SetMemoryAddress(pHandle->rxDMA, pHandle->rxChannel, (uint32_t)buffer);
  LL_DMA_SetDataLength(pHandle->rxDMA, pHandle->rxChannel, length);

  LL_DMA_EnableChannel(pHandle->rxDMA, pHandle->rxChannel);
}

/**
  * @brief  Sets IDLE state : no transmission on going.
  *
  * @param  pHandle Handler of the current instance of the UASPEP component
  */
void UASPEP_IDLE_ENABLE(void *pHWHandle)
{
  UASPEP_Handle_t *pHandle = (UASPEP_Handle_t *)pHWHandle; //cstat !MISRAC2012-Rule-11.5
  LL_USART_ClearFlag_IDLE(pHandle->USARTx);
  LL_USART_EnableIT_IDLE(pHandle->USARTx);
}

/**
  * @}
  */

/**
  * @}
  */
/************************ (C) COPYRIGHT 2024 STMicroelectronics *****END OF FILE****/

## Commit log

2024-08-02 Started V1 Schematics
    [DRV8305Breakout.kicad_sch, EasyESCV1_DRV8305.kicad_pcb, EasyESCV1_DRV8305.kicad_sch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]
2024-08-06 Finished REV1 Schematic Awaiting Review
    [DRV8305Breakout.kicad_sch, EasyESCV1_DRV8305.kicad_sch, MainConnector.kicad_sch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]
2024-08-06 Updated Some Errors in Schematic
    [EasyESCV1_DRV8305.kicad_sch, TMS320F28027FBreakout_sch.kicad_sch]
2024-08-06 Fixed issue with fet symbol and started layout
    [DRV8305Breakout.kicad_sch, EasyESCV1_DRV8305.kicad_pcb, MainConnector.kicad_sch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]
2024-08-07 Started Layout
    [DRV8305Breakout.kicad_sch, EasyESCV1_DRV8305.kicad_pcb]
2024-08-13 Fixed Naming Scheme
    [DRV8305Breakout.kicad_sch, EasyBLDCV1_DRV8305.kicad_pcb, EasyBLDCV1_DRV8305.kicad_sch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]
2024-08-13 Updated Schematic With Missing Footprints
    [EasyBLDCV1_DRV8305.kicad_pcb, MainConnector.kicad_sch, TMS320F28027FBreakout_sch.kicad_sch]
2024-08-13 Progress on MCU Breakout
    [DRV8305Breakout.kicad_sch, EasyBLDCV1_DRV8305.kicad_pcb, TMS320F28027FBreakout_sch.kicad_sch]
2024-08-13 Continued work on layout
    [EasyBLDCV1_DRV8305.kicad_pcb]
2024-08-13 Started DRV Breakout
    [EasyBLDCV1_DRV8305.kicad_pcb]
2024-08-13 Continued work on drv8305 breakout
    [EasyBLDCV1_DRV8305.kicad_pcb]
2024-08-14 Initial Layout For Mosfets
    [EasyBLDCV1_DRV8305.kicad_pcb]
2024-08-14 Finished Mosfet Layout
    [EasyBLDCV1_DRV8305.kicad_pcb]
2024-08-14 Started layout between drv and fets
    [EasyBLDCV1_DRV8305.kicad_pcb]
2024-08-14 Started Connecting Microcontroller
    [EasyBLDCV1_DRV8305.kicad_pcb]
2024-08-15 Continued layout work
    [EasyBLDCV1_DRV8305.kicad_pcb]
2024-08-15 Finished Initial Layout
    [EasyBLDCV1_DRV8305.kicad_pcb, MainConnector.kicad_sch]
2024-08-15 Fixed ref des
    [EasyBLDCV1_DRV8305.kicad_pcb]
2024-08-15 Fixed More DRC started final layout
    [EasyBLDCV1_DRV8305.kicad_pcb, MainConnector.kicad_sch]
2024-08-15 Updated PCB Graphics and Layout
    [EasyBLDCV1_DRV8305.kicad_pcb, MainConnector.kicad_sch]
2024-08-15 Created Logos
    [BottomLogo.dxf]
2024-08-16 Updated Inductor and excluded tps from BOM
    [DRV8305Breakout.kicad_sch, EasyBLDCV1_DRV8305.kicad_pcb, TMS320F28027FBreakout_sch.kicad_sch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]
2024-08-25 Colored main connector
    [MainConnector.kicad_sch]
2024-09-04 Fixed errors with silkscreen overlaping vias. Generated final gerbers.
    [DRV8305Breakout.kicad_sch, EasyBLDCV1_DRV8305.kicad_pcb, EasyBLDCV1_DRV8305.kicad_sch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]
2024-09-06 Changed main connector pinout to improve signal integrity
    [EasyBLDCV1_DRV8305.kicad_pcb, MainConnector.kicad_sch]
2024-09-06 Fixed Silkscreen DRC Errors
    [EasyBLDCV1_DRV8305.kicad_pcb]
2024-09-07 JTAG Connector Changed
    [EasyBLDCV1_DRV8305.kicad_pcb, MainConnector.kicad_sch, TMS320F28027FBreakout_sch.kicad_sch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]
2024-10-19 Created V2 Project Files
    [BottomLogo.dxf, DRV8305Breakout.kicad_sch, EasyBLDCV2_MCF8329.kicad_pcb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]
2024-10-20 Deleted V1 Relics, redid power stage
    [DRV8305Breakout.kicad_sch, EasyBLDCV2_MCF8329.kicad_pcb, EasyBLDCV2_MCF8329.kicad_sch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]
2024-10-24 Broke-out mcf8329
    [TMS320F28027FBreakout_sch.kicad_sch]
2024-10-24 Added comments to schematic
    [EasyBLDCV2_MCF8329.kicad_sch, MainConnector.kicad_sch, TMS320F28027FBreakout_sch.kicad_sch]
2024-10-25 Finished schematic
    [DRV8305Breakout.kicad_sch, EasyBLDCV2_MCF8329.kicad_sch, MainConnector.kicad_sch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]
2024-10-25 Assigned footprints, created bom
    [DRV8305Breakout.kicad_sch, EasyBLDCV2_MCF8329.kicad_pcb, EasyBLDC_V2_BOM.xlsx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]
2024-10-26 Started component layout
    [EasyBLDCV2_MCF8329.kicad_pcb]
2024-10-26 Redid Power Fills
    [DRV8305Breakout.kicad_sch, EasyBLDCV2_MCF8329.kicad_pcb]
2024-10-26 More work on layout
    [EasyBLDCV2_MCF8329.kicad_pcb, TMS320F28027FBreakout_sch.kicad_sch]
2024-10-30 Added footprints for ESC and additional connectors
2024-10-30 Adjusted power traces
    [EasyBLDCV2_MCF8329.kicad_pcb]
2024-11-01 Finished Silscreen
    [EasyBLDCV2_MCF8329.kicad_pcb, MainConnector.kicad_sch, TMS320F28027FBreakout_sch.kicad_sch]
2024-11-01 Changed Stackup
    [EasyBLDCV2_MCF8329.kicad_pcb]
2024-11-03 Finished V2
    [EasyBLDCV2_MCF8329.kicad_pcb, bom.csv, designators.csv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]
2024-11-15 Updated BOM
    [EasyBLDC_V2_BOM.xlsx]
2024-12-08 First Configuration File
    Motor spins but needs additional tuning
2024-12-23 Updated Step File
    [EasyBLDCV2_MCF8329.step]
2025-01-15 Added Components for Version 3
    [BottomLogo.dxf, DRV8305Breakout.kicad_sch, EasyBLDCV3_STM32.kicad_pcb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]
2025-01-20 Got stm dev board running
2025-01-21 Added footprints and began schematic for new gate drive
    [DRV8305Breakout.kicad_sch, EasyBLDCV3_STM32.kicad_sch, TMS320F28027FBreakout_sch.kicad_sch]
2025-01-28 Worked on gate drive schematic
    [DRV8305Breakout.kicad_sch, TMS320F28027FBreakout_sch.kicad_sch]
2025-02-22 Created V4 Project
    [BottomLogo.dxf, DRV8305Breakout.kicad_sch, EasyBLDCV4_STSPIN32F0A.kicad_pcb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]
2025-02-23 Finished Schematic Assigned Footprints
    [DRV8305Breakout.kicad_sch, MainConnector.kicad_sch, TMS320F28027FBreakout_sch.kicad_sch]
2025-02-23 More layout progress
    [EasyBLDCV4_STSPIN32F0A.kicad_pcb]
2025-02-23 Layout almost final
    [EasyBLDCV4_STSPIN32F0A.kicad_pcb]
2025-02-23 Design finished, ready for review
    [EasyBLDCV4_STSPIN32F0A.kicad_pcb, MainConnector.kicad_sch, TMS320F28027FBreakout_sch.kicad_sch]
2025-02-24 Fixed DRC Errors. Ready for review
    [DRV8305Breakout.kicad_sch, EasyBLDCV4_STSPIN32F0A.kicad_pcb]
2025-02-24 Updated Board According to Dirk Kaisers Review
    [EasyBLDCV4_STSPIN32F0A.kicad_pcb, bom.csv, designators.csv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]
2025-03-25 updated some shit idk
    [TMS320F28027FBreakout_sch.kicad_sch]
2025-03-26 Changed out 0201 resistors, production version
    [DRV8305Breakout.kicad_sch, EasyBLDCV4_STSPIN32F0A.kicad_pcb, EasyBLDC_V4_BOM.xlsx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]
